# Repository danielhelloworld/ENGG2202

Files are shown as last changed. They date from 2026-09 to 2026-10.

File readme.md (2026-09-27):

# ENGG2202 MaixCAM 2 Project

This repository contains the MaixCAM 2 vision-tracking prototype, its system architecture, and a local developer workbench for device monitoring.

## Components

- [Tracker architecture](maixcam2_drone_tracker_architecture.md) — system boundaries, runtime flow, and staged development plan.
- [Person-tracking application](maixcam2_person_tracker/README.md) — Stage 1 YOLO person detection, target association, bearing estimation, and safe vision-only gimbal flow.
- [Developer workbench](workbench/README.md) — local monitoring dashboard, MJPEG stream proxy, telemetry schema, extension points, and setup instructions.
- `Daniel's code/` — existing ENGG2202 project files.

The workbench is a development monitor. Camera capture and inference remain on the MaixCAM 2; the Mac gateway displays the video and receives telemetry without taking ownership of the vision loop.

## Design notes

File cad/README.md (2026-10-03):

# 云台机械件与 MaixCAM2 快拆转接台

同步日期：2026-10-03。本目录包含相机转接台的源模型、可编辑 Fusion 文件、STEP、单件 STL、缩略图、复建脚本及验证记录，以及此前两个版本的电机支架与连接板。同步清单和 SHA-256 位于 [SYNC_MANIFEST.json](SYNC_MANIFEST.json)。

## 快速定位打印零件

- [V3 USB 优化版单件 STL](gimbalconnector/STL_单件打印_2026-10-03/01_V3_USB优化版/)：当前预留 USB 空间的版本。
- [V2 原位置加强版单件 STL](gimbalconnector/STL_单件打印_2026-10-03/02_V2_原位置加强版/)：保留相机原位置，增加底部热铆柱与侧向热铆销。
- [V2 原版单件 STL](gimbalconnector/STL_单件打印_2026-10-03/03_V2_原版/)：最初确认长边对齐的版本。
- [单件打印说明](gimbalconnector/STL_单件打印_2026-10-03/README_打印说明.md)与[打印清单](gimbalconnector/STL_单件打印_2026-10-03/打印清单.csv)。
- [离线零件索引 HTML](gimbalconnector/零件缩略图_2026-10-03/零件索引.html)：克隆或下载仓库后用浏览器打开，可筛选并访问对应 STL。GitHub 页面显示 HTML 源码，可直接查看下方 PNG 总览。

每套选择一个底座和一种相机快装板。加强版与 USB 版另需 **2 颗独立侧向热铆销**；铆销 STL 只有一颗。底部热铆柱与底座、四角固定立边与相机板分别一体打印。金属螺丝不作为打印件。

### V3 USB 优化版

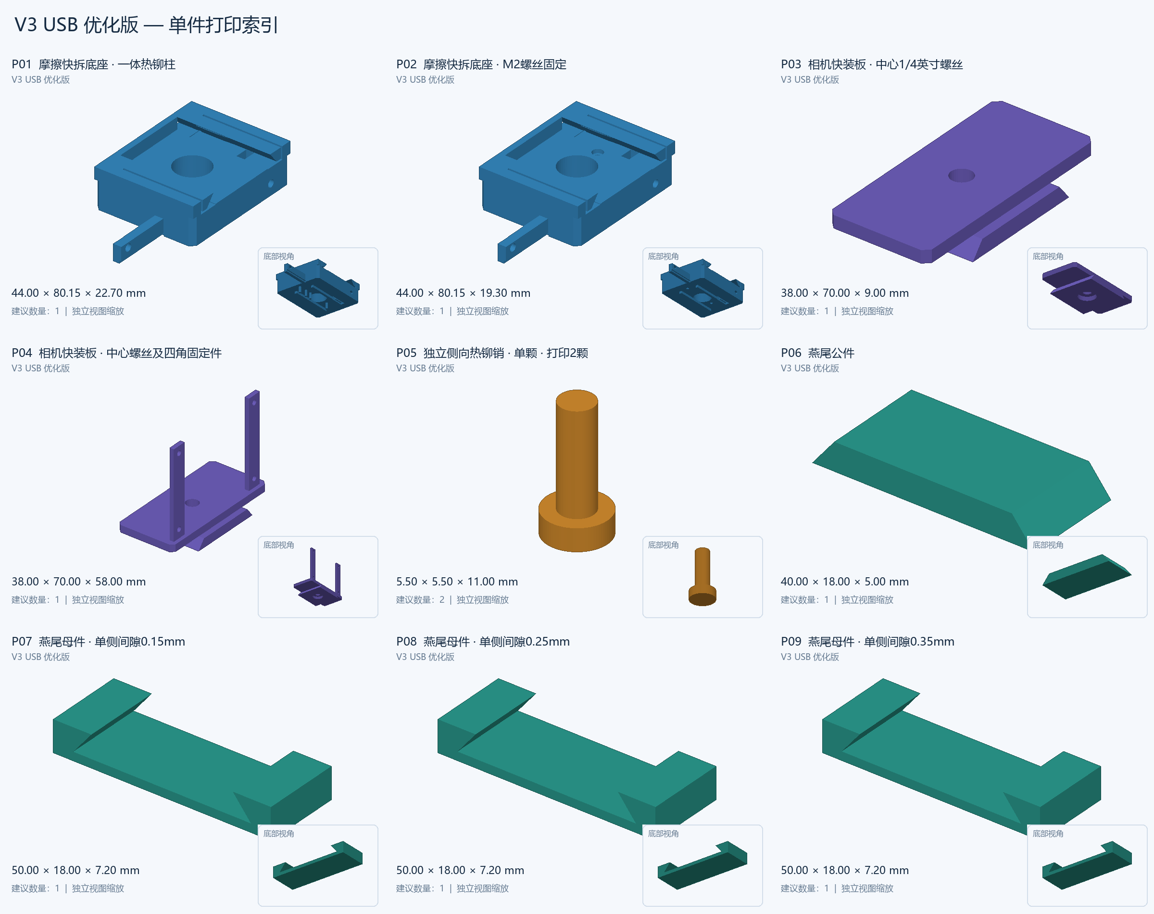
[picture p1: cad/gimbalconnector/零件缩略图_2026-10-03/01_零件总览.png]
V3 USB 单件总览


### V2 原位置加强版

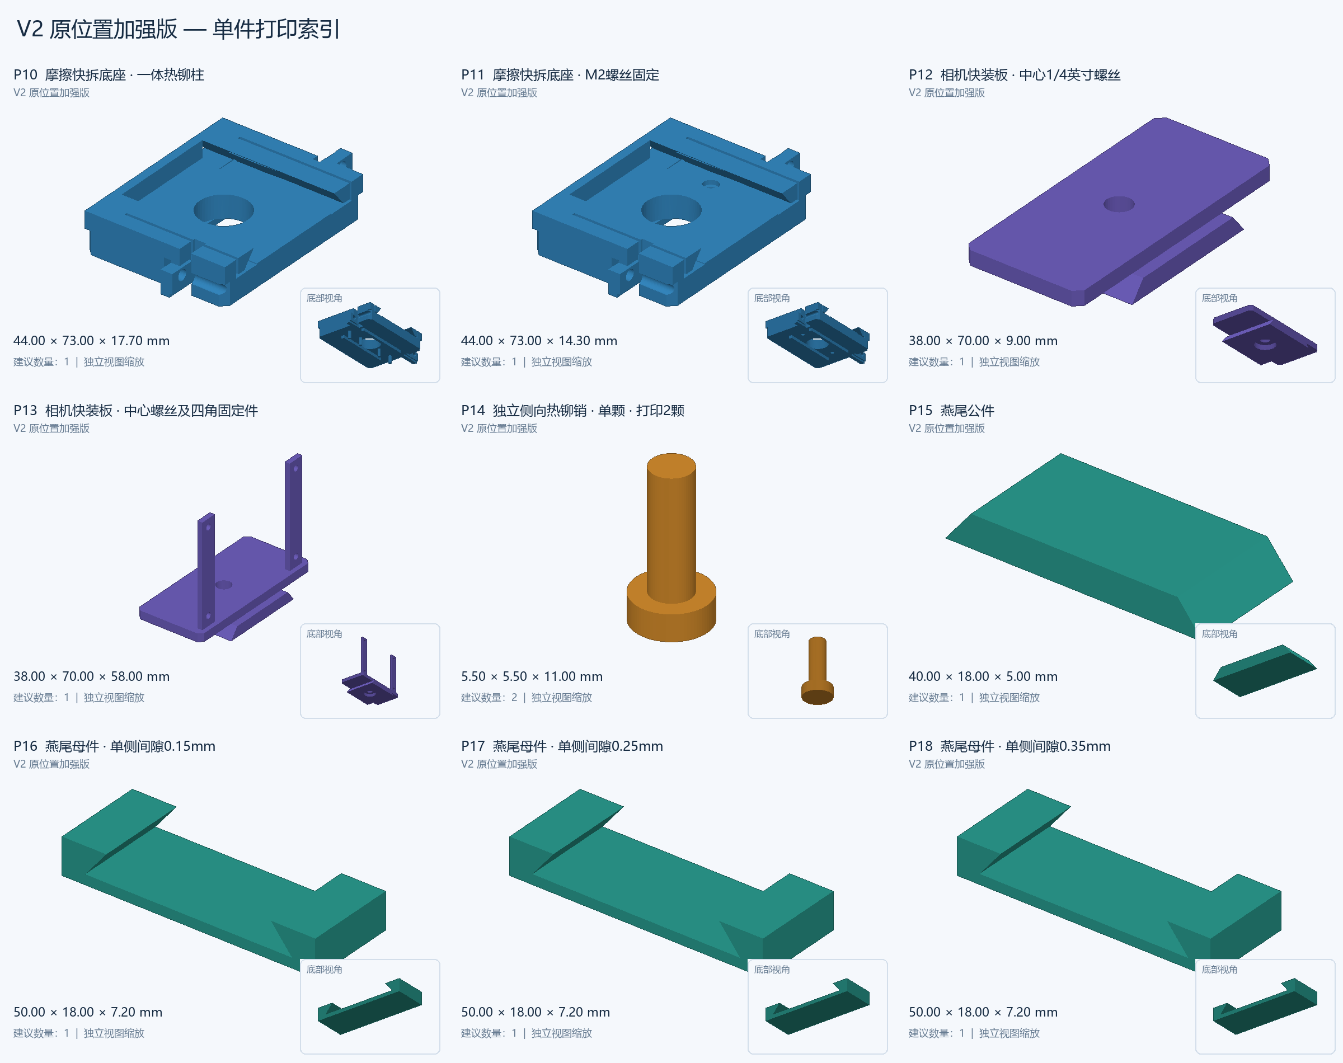
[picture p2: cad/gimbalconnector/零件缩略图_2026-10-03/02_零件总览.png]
V2 加强版单件总览


### V2 原版

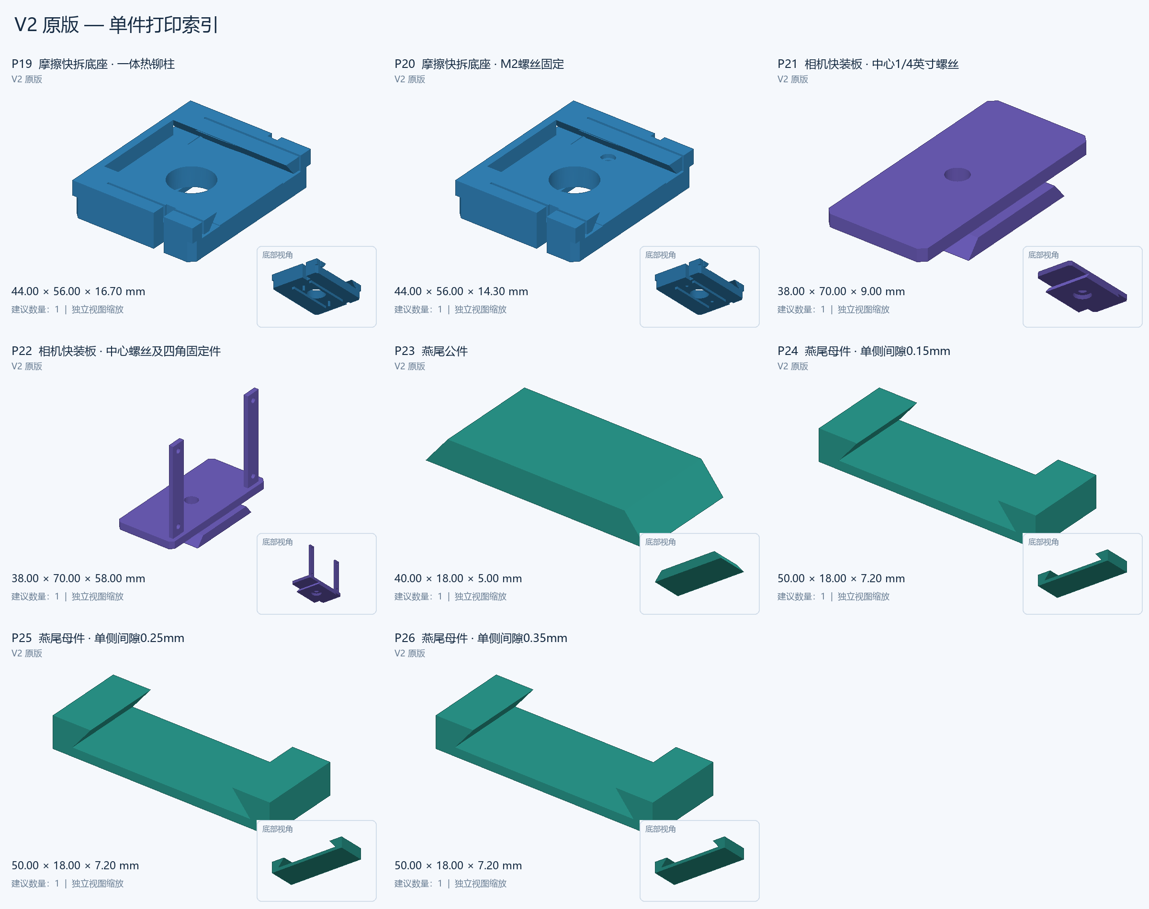
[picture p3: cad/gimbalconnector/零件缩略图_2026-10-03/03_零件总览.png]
V2 原版单件总览


V1 相机方向未采用，仍保留在历史目录，详见 [项目说明](gimbalconnector/README.md)。

## 以前两个版本的电机支架

按本地原文件名称分组，不修改模型或打印坐标：

| 版本 | 电机支架 | 连接板 |
|---|---|---|
| 原版 V1 | [电机支架.stl](motor_brackets/v1/电机支架.stl) | [电机支架连接板.stl](motor_brackets/v1/电机支架连接板.stl) |
| 第二版 V2 | [电机支架2.stl](motor_brackets/v2/电机支架2.stl) | [电机支架连接板2.stl](motor_brackets/v2/电机支架连接板2.stl) |

电机支架的 V1/V2 是这四个原始文件的版本标签，与相机快拆转接台 V1/V2/V3 独立。没有根据版本号推定两者互换兼容性。

## 编辑与验证

[转接台项目入口](gimbalconnector/README.md)介绍各版 Fusion/STEP、源模型及建模脚本；[加强版和 USB 空间说明](gimbalconnector/README_加强版与USB优化.md)介绍孔位、热铆顺序、USB 插头包络和螺丝空间。

相机转接台的 34 个单件 STL 已完成封闭性、单一连通性及尺寸保持检查，34 张缩略图逐一对应 STL，索引筛选已检查。本次四个电机支架文件仅进行原样复制、二进制 STL 格式和哈希核验。实际打印、热铆强度、摩擦保持力及完整云台运动尚未验证。

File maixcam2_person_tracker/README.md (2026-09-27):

# MaixCAM 2 Person-Tracking Gimbal

This project is the Stage 1 closed-loop validation build for a future airborne-drone tracker. It runs on a MaixCAM 2, detects one person with YOLO11, estimates the person's world bearing, and commands a two-axis WHEELTEC F32C brushless gimbal over 3.3 V TTL UART.

The project is intentionally divided so the person detector can later be replaced by a custom drone detector without changing the state estimator, loss-recovery state machine, gimbal controller, motor protocol, or telemetry pipeline.

## Current stage

Implemented:

- YOLO11 person detection using COCO class ID `0`;
- stable single-person selection when several people are visible;
- pixel-to-bearing conversion using configurable camera field of view;
- dependency-free constant-angular-velocity Kalman filtering;
- `BOOT`, `ACQUIRE`, `TRACK`, `COAST`, `SEARCH`, and `FAULT` states;
- prediction during short detector loss;
- expanding local search after the coast interval expires;
- acceleration- and rate-limited gimbal position commands;
- F32C direct multi-turn position protocol and angle feedback parsing;
- non-blocking CSV telemetry and display overlays;
- a vision-only mode for safe first execution.
- a headless default mode with one-second console status reports.

Deferred to later stages:

- MixFormerV2 appearance tracking between YOLO frames;
- frame-time gimbal-pose interpolation;
- IMU rate fusion;
- dynamic high-resolution ROI detection;
- custom drone YOLO model and appearance-based reacquisition;
- full 3D camera-to-gimbal rotation calibration.

## Safety default

`config.py` ships with:

```python
enabled: bool = False
```

The application will run the complete vision, target-selection, estimation, state-machine, overlay, and logging pipeline, but it will not open UART4 or move the gimbal.

The display is also disabled by default so the application can be started over SSH when the device's display service is already occupied. Detection count, selected-person pixels, estimated world bearing, mode, and gimbal pose are printed once per second. Set `UiConfig.enabled = True` to request the onboard display when it is available.

Do not enable the gimbal until motor IDs, axis directions, zero offsets, mechanical soft limits, wiring, and power supplies have been checked using the procedure in [docs/BRINGUP.md](docs/BRINGUP.md).

## Hardware interface

| Signal | MaixCAM 2 | F32C gimbal |
|---|---|---|
| TX | A21 / UART4_TX | RX |
| RX | A22 / UART4_RX | TX |
| Ground | GND | GND |

UART settings are `115200 8N1`. MaixCAM 2 and F32C use 3.3 V logic. Do not apply 5 V logic to the MaixCAM pins.

Use separate regulated power paths:

- F32C motors: 8-15 V, normally a 3S supply;
- MaixCAM 2: stable regulated 5 V;
- common signal ground between the two systems.

Do not hot-plug any F32C connector.

## Model

The default model path is:

```text
/root/models/yolo11n.mud
```

The model must be a MaixCAM 2 YOLO11 package containing the `.mud` file and every referenced `.axmodel` file. Its label list must use the standard COCO order, where `person` is class ID `0`.

If the model is stored elsewhere, change `ModelConfig.path` in `config.py`.

## Deployment

1. Copy the entire `maixcam2_person_tracker` directory to the MaixCAM 2 with MaixVision.
2. Confirm the YOLO11 model exists at the configured path.
3. Open and run `main.py` from the project directory.
4. Verify that a person receives a green detection box and that the mode progresses from `ACQUIRE` to `TRACK`.
5. Review the yellow predicted point and the CSV log at `/root/logs/person_tracker.csv`.
6. Stop the application and complete the motor bring-up checklist before setting `GimbalConfig.enabled` to `True`.

The Mac is a development and monitoring host only. The real-time loop runs entirely on the MaixCAM 2.

## Workbench integration

The optional [MaixCAM 2 Workbench](../workbench/README.md) provides a browser dashboard, MJPEG proxy, telemetry categories, and runtime status. It does not take ownership of the camera or inference loop.

To publish status, set the `endpoint` default inside `WorkbenchConfig` in `config.py` to the Mac USB-network address ending in `/api/telemetry`:

```python
endpoint: str = "http://10.177.5.100:8760/api/telemetry"
```

The publisher is disabled when the endpoint is empty. When enabled, it sends the newest camera, person detection, tracking, gimbal, model, and process snapshot from a background thread. A disconnected dashboard does not block the vision loop. Keep the workbench gateway bound to the Mac's USB-network interface; its telemetry endpoint is unauthenticated.

## Configuration that must be measured

The values in `config.py` are conservative starting points, not final calibration values:

- camera horizontal and vertical field of view;
- pan and tilt motor direction signs;
- logical zero offsets;
- pan and tilt mechanical soft limits;
- stable maximum rate and acceleration under the installed payload;
- detector confidence and reacquisition gate;
- coast and search timing.

## Runtime behavior

The tracker requires three consecutive person detections before commanding the gimbal. During a brief miss it enters `COAST` and commands the predicted future bearing. If the miss lasts too long or uncertainty grows too large, it enters `SEARCH` and scans an expanding region around the predicted bearing. If local search fails, the old track is cleared and the system returns to full-frame acquisition.

The F32C motors run their internal position and speed loops. MaixCAM 2 sends direct multi-turn position targets at up to 50 Hz by default and polls total-angle feedback from each motor in turn.

## Project layout

```text
main.py                         Application entry point
application.py                  Real-time orchestration
config.py                       All tunable values
domain.py                       Shared data contracts
perception/detector_yolo.py     YOLO11 adapter
perception/target_selector.py   Single-person association
estimation/camera_model.py      Pixel/bearing conversion
estimation/target_filter.py     Constant-velocity Kalman filter
control/state_machine.py        Loss and recovery behavior
control/search_pattern.py       Expanding local scan
control/gimbal_controller.py    Command prediction and motion limits
drivers/f32c_protocol.py        Binary F32C protocol
drivers/gimbal_uart.py          UART ownership and motor state
telemetry/csv_logger.py         Bounded asynchronous logging
telemetry/mjpeg_stream.py       Annotated MJPEG camera endpoint
telemetry/workbench_publisher.py Optional asynchronous desktop telemetry
telemetry/overlay.py            On-screen diagnostics
docs/ARCHITECTURE.md            Design and module boundaries
docs/BRINGUP.md                 Safe hardware activation procedure
```

## Moving to the drone stage

Replace `YoloPersonDetector` with a detector that returns the same `Detection` data type. Change the model path, class ID, label, confidence threshold, and reacquisition gate. The rest of the application does not depend on the target category.

For a distant drone, use at least a `640x480` model input, collect data through the actual lens and sky background, and expect optics and motion blur to become limiting factors before NPU throughput.

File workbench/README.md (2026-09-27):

# MaixCAM 2 Workbench

The workbench is a local developer console for a MaixCAM 2 vision project. It combines the device MJPEG camera feed with structured telemetry and process health on one page. The browser talks only to the workbench gateway; the gateway proxies the device video stream and accepts telemetry snapshots.

## Features

- Overview page for camera, detections, tracking state, gimbal feedback, and running file.
- Live camera page with the annotated MJPEG feed.
- Data explorer organized into vision, tracking, gimbal, and system categories.
- Runtime view for the active entry point, process ID, uptime, model, and device services.
- Device connection settings for IP address and video-stream port.
- Extensible JSON telemetry schema with namespaced `extensions` data.
- Server-sent events for browser updates; no third-party JavaScript packages are required.

## Architecture

```text
MaixCAM 2 tracker
  ├── MjpegStreamer ── HTTP MJPEG :8080 ───────────────┐
  └── WorkbenchPublisher ── POST /api/telemetry ───────┤
                                                       ▼
Mac Workbench gateway :8760 ── same-origin MJPEG proxy + SSE ── Browser UI
```

The MaixCAM 2 tracker remains responsible for camera capture and inference. `WorkbenchPublisher` sends a small latest-value snapshot on a background thread so a disconnected workbench does not block the vision loop. The Mac gateway keeps the newest snapshot in memory and exposes a stable browser API. The web UI renders registered categories and automatically includes unregistered metrics under extension namespaces.

## Start the workbench

The MaixCAM 2 USB network commonly gives the device `10.177.5.1` and the Mac `10.177.5.100`. Confirm the Mac address in Network settings before starting the gateway. Replace it below if the USB interface uses another address.

```bash
cd ENGG2202-github
python3 workbench/server.py --host 10.177.5.100 --port 8760 --device-ip 10.177.5.1 --video-port 8080
```

Open `http://10.177.5.100:8760/` in a browser. The gateway must bind to an address reachable by both the browser and MaixCAM 2. Bind to the Mac's USB-network interface only. The telemetry endpoint has no authentication and should not be exposed on a shared network or the public internet.

## Connect the MaixCAM 2 tracker

Set `WorkbenchConfig.endpoint` in `maixcam2_person_tracker/config.py` to the Mac USB-network address shown in the workbench's **Connection Settings** page:

```python
class WorkbenchConfig:
    endpoint = "http://10.177.5.100:8760/api/telemetry"
```

In the current code, `WorkbenchConfig` is a frozen dataclass. Set the `endpoint` field in its declaration, or provide `MAIX_WORKBENCH_URL` in the MaixCAM 2 process environment. Then start `maixcam2_person_tracker/main.py` on the device. The tracker starts its annotated MJPEG endpoint on port `8080` and publishes camera, person-detection, tracking, gimbal, model, and process metrics to the workbench.

The initial gimbal setting remains disabled. Starting the dashboard does not start or stop the tracker and does not send motor commands.

## Telemetry schema

Each `POST /api/telemetry` payload is a JSON object with a `schema_version` and category objects:

```json
{
  "schema_version": 1,
  "runtime": {"running": true, "script": "main.py", "pid": 123, "uptime_seconds": 12.5, "model_path": "/root/models/yolo11n.mud"},
  "camera": {"available": true, "width": 640, "height": 480, "fps": 15.0},
  "vision": {"person_count": 1, "selected_label": "person", "confidence": 0.87, "center_x": 320, "center_y": 240},
  "tracking": {"mode": "TRACK", "azimuth_deg": 0.2, "elevation_deg": -1.1, "azimuth_rate_deg_s": 0.0, "elevation_rate_deg_s": 0.3},
  "gimbal": {"enabled": false, "pan_deg": 0.0, "tilt_deg": 0.0, "pan_valid": true, "tilt_valid": true},
  "system": {"camera_available": true, "npu_ready": true},
  "extensions": {"depth": {"meters": 1.4}}
}
```

Use `extensions.<module-name>` for new features that do not belong to an existing category. The Data Explorer adds each namespace as a tab and lists its metrics without requiring a schema migration. For richer labels, units, charts, or controls, extend `CATEGORY_DEFS` and `METRICS` in `web/app.js`, then add the matching UI module in `web/`.

## HTTP API

| Route | Method | Purpose |
|---|---|---|
| `/api/health` | GET | Gateway health check |
| `/api/state` | GET | Latest telemetry snapshot and connection age |
| `/api/events` | GET | Server-sent state updates |
| `/api/config` | GET/POST | Read or update device IP and stream port |
| `/api/telemetry` | POST | Ingest the device telemetry snapshot |
| `/api/camera/stream` | GET | Same-origin proxy for the device MJPEG stream |

Telemetry is considered connected while a snapshot has arrived within the last three seconds. The latest snapshot is kept in memory; the gateway does not persist telemetry or camera video to disk.

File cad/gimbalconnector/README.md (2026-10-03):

# MaixCAM2 云台快拆转接台

## 选择版本

| 目录 | 用途 | 状态 |
|---|---|---|
| `output_v3_usb/` | 相机外移 20 mm，USB 侧留约 25.5 mm 空间，4 根底柱和 2 颗侧向销 | 当前 USB 优化版 |
| `output_v2_reinforced/` | 保持 V2 相机位置，增加底部热铆柱和侧向固定 | 原位置加强版 |
| `output_v2/` | 已确认的长边对齐版本 | 原版完整保留 |
| `output_v1/` | 早期方向试作 | 历史参考，未采用 |

## 打开与打印

- 在选定版本目录中打开 `MaixCAM2_quick_release_assembly.f3d`，可在 Fusion 中查看和编辑总装。
- STEP 用于交换实体，STL 用于切片；请打印选定零件，不要打印包含相机、金属支架参考体的总装。
- 加强版和 USB 版的热铆组合：`receiver_heat_stake.stl` + 一种 `camera_plate*.stl` + **2 颗** `side_heat_rivet_print_2.stl`。铆销 STL 本身只有一颗，切片数量设为 2。
- `receiver_M2_bolt.stl` 为螺钉固定的备用底座；`fit_coupon_*.stl` 为间隙试件。
- `assembly_preview.png` 为装配预览；USB 版另有 `USB_clearance_preview.png`。

详细尺寸、材料起始设置、螺丝长度和热铆顺序见 [加强版与 USB 优化说明](README_加强版与USB优化.md)及[原快拆设计说明](README_快拆转接台.md)。模型和网格检查已完成，实际摩擦保持力、热铆强度及线缆弯曲仍需试装。

## 源文件与复建工具

| 文件或目录 | 内容 |
|---|---|
| `MaixCAM2_3.0.step` | 本次采用的相机源模型 |
| `云台连接件.step` | 原云台支架源模型 |
| `3D_MaixCam2_379C_2025-09-16.step` | 较早的相机参考模型 |
| `quick_release_tool/` | Fusion 建模脚本、配置、网格校验脚本和验证记录 |
| 各版本的 `build_report.json`、`mesh_validation.json` | 几何与打印网格检查结果 |

Fusion 脚本使用 Fusion 自带的 Python 和 `adsk` API，不依赖本项目的独立虚拟环境。`validate_mesh.py` 和 `validate_optimized.py` 仅使用 Python 标准库。

当前 `command.json` 指向 USB 版复建。运行脚本会写入对应输出目录；已有文件需要另留版本时，应先调整输出目录。原相机和云台连接件文档需在 Fusion 中打开。

## 缓存清理

2026-10-03 清理记录位于 `cleanup_2026-10-03.json`。清理对象为未使用的 `cad_venv/`、脚本 `__pycache__/`、可重新生成的 `inspection.json` 和过期 `error.txt`，采用回收站保留恢复机会。版本目录、源模型、脚本和正式检查报告保持原路径。

后续运行 Python 可能重新生成 `__pycache__/`；执行 Fusion 的 `inspect` 模式会重新生成检查快照。它们不需要作为交付文件保存。

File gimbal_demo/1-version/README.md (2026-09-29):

# WHEELTEC F32C 双轴追踪控制 Demo

本 demo 根据资料包中的 2026-07-18 二自由度云台手册、2026-07-21 F32C 电机手册、STM32/TI 位置与速度例程，以及 STM32F4 绘图例程整理。它负责两台电机和视觉闭环，不包含无人机检测模型，也不包含激光发射控制。

## 轴与协议

- X 轴：底部 yaw，默认电机 ID `1`。
- Y 轴：上部 pitch，默认电机 ID `2`。
- TTL 逻辑电平 `3.3 V`，串口 `115200-8-N-1`。
- K230 TX 接云台 RX，K230 RX 接云台 TX，信号地与电机电源地必须共地。
- 电机主电源 `8~15 V`，推荐 3S；不要从 K230 给电机主回路供电。
- 所有接口禁止热插拔；滑环电流能力有限，K230 供电需先核对实际峰值电流。
- 相邻协议帧至少间隔 `1 ms`。本 demo 默认 `2 ms`。
- 高频修改目标位置使用手册建议的“多圈位置直通模式”`0x0003`。

默认的 Y 轴死角宽度为 `120°`，中心位于逻辑 `180°`（云台后方），并预留两侧各 `2°` 安全边界，因此控制器实际允许 `-118°~+118°`。可通过 `--y-dead-width`、`--y-dead-center` 和 `--y-dead-margin` 修改。如果实际机械零点不同，应先低速点动确认死角中心再改参数。

## 第一次运行

先不要连接电机，用协议模拟验证：

```powershell
cd C:\Users\w.yingxi\Desktop\ENGG2202\f32c_gimbal_python_demo
python demo.py --dry-run manual --x 15 --y 10
python demo.py --dry-run simulate --seconds 3
python -m unittest -v
```

PC 通过 USB-TTL 控制时：

```powershell
python -m pip install -r requirements.txt
python demo.py --port COM5 --speed 20 manual --x 5 --y 5
```

首次带硬件测试请把云台固定牢，移除激光器和贵重负载，把角度限制在小范围。若方向相反，使用 `--x-sign -1` 或 `--y-sign 1`，不要交换电源线。

## 接入 K230 检测结果

PC/进程间可以向标准输入逐行发送检测框中心：

```powershell
'{"cx":400,"cy":220,"width":640,"height":480}' | python demo.py --port COM5 track-stdin
```

未检测到目标时发送：

```json
{"detected": false, "width": 640, "height": 480}
```

在 K230 上，按开发板的 pinmux 创建 `machine.UART` 后，将 YOLO/检测器输出的目标框中心接到 `k230_integration.run_tracking()`。检测回调的返回值为：

```python
(target_center_x, target_center_y, frame_width, frame_height)
```

没有目标则返回 `None`。如果同一帧有多个候选目标，应在检测侧先固定一个 track ID，避免控制器在目标间跳变。

## 控制流程

1. 发送一次唤醒字节并等待电机启动 1.5 秒。
2. 依次使能 ID 1 和 ID 2。
3. 两轴选择多圈位置直通模式，设置位置运动速度。
4. 分别读取当前多圈角度，将其作为软件零点，避免启动时突然回到电机上电零点。
5. K230 每帧给出检测框中心；控制器把像素误差按相机 FOV 换算为角度误差，经比例、像素死区和角速度限制后下发两轴目标。
6. Y 轴命令始终被限制在配置的连续安全区间内。
7. 退出时发送两轴失能命令。

## 重要边界

- 代码只解决“检测结果到双轴角度”的闭环。检测模型、目标身份保持、云台/相机外参、镜头畸变和飞行目标提前量需要在实际系统中标定。
- 相机水平/垂直视场角默认 `70°/43°`，必须替换为实际镜头参数。
- 激光对眼睛、车辆和航空器均有严重风险。调试时仅使用低功率可见指示光并配合封闭式挡光靶；不要照射真实飞行器或天空。

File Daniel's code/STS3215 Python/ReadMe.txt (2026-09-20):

Hi guys, This is Kelvin. Hope you are doing well with your miniprojects.

If you are working on the STS3215 projects and got stuck, you may refer to this folder.
You can either run the code inside VS code or directly in the terminal just like what we did in the workshops

Here is a guide of what the files inside this folder does:

"ENGG_1101_STS3215" is the main folder that stores all the python scripts and library packages
	Inside the folder there are 3 important python scripts:
	
	1. "change_id.py" in which you have to input the orginal and new ID:

		SCS_ID = 1            # SCServo ID : 1
		NEW_ID = 2             #Change the Servo ID

	2. "ENGG1101_2servo_write.py" where I already helped you setup ID = 1 and ID = 2 for the two servos you need
		what you need to do is just run the code and input the positions for servo 1 and servo 2
		(For your projects you would need to modify the input part to some snsor vales - ToF or camea)

	3. "read_write.py" - this is the original python code that reads and write the position for a single STS3215 servo. 
		you can take some reference from it and modify using the help of AI

Also, one IMPORTANT thing:
For each of the python scripts I mentioned above, you would need to change the BAUDRATE as well as the DEVICENAME (which is the communication port on the raspberry pi)

You would have to change these lines of code:(Set Baudrate to 115200 and check the raspberry pi & servo driver communication port using the "dmesg" command in terminal)  

	BAUDRATE   = 115200           # Must match the ESP32's serial forwarding baudrate
	# Check Raspberry Pi serial port with "dmesg" command and look for the port connectng to cp210x
	DEVICENAME = '/dev/ttyUSB1'   # Change to your port (e.g., '/dev/ttyUSB0', 'COM3')  

*** If you have any futher questions, feel free to come to the helpdesks on tuesdays and fridays from 1400 to 1700. You could also email me and ryan for more helpdesk sessions or help ***

P.S. Ryan's email: ruoyu@hku.hk ; My email: ckchancd@hku.hk

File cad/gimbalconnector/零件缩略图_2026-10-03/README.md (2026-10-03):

# 单件打印缩略图

用浏览器打开 `零件索引.html`，可按版本、类型和名称筛选，点击“获取 STL”访问对应文件。默认显示当前 V3 USB 版。

`缩略图/` 包含每个单件的 PNG，`01_零件总览.png` 至 `04_零件总览.png` 为各版总览。图片来自真实 STL 网格，每件有上方和底部两个视角。

原有项目文件均未改动。请保持本目录与 `STL_单件打印_2026-10-03/` 并列，以便索引内的 STL 链接正常工作。

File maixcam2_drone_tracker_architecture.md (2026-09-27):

# MaixCAM 2 Drone-Tracking System Architecture

The approved architecture has been converted into an English implementation project at:

- [Project README](maixcam2_person_tracker/README.md)
- [Software architecture](maixcam2_person_tracker/docs/ARCHITECTURE.md)
- [Hardware bring-up procedure](maixcam2_person_tracker/docs/BRINGUP.md)

## System direction

The final system uses a MaixCAM 2, one camera, and a two-axis WHEELTEC F32C brushless gimbal. MaixCAM 2 owns perception, target-state estimation, loss recovery, and gimbal target generation. Each F32C motor retains responsibility for its internal position and speed loops.

The runtime chain is:

```text
Camera
  -> YOLO detector
  -> single-target association
  -> world-bearing Kalman filter
  -> TRACK / COAST / SEARCH state machine
  -> bounded position trajectory
  -> F32C direct multi-turn position commands
```

Stage 1 uses the COCO `person` class to validate the complete visual closed loop. The later drone model will implement the same `Detection` interface, allowing the estimator, controller, motor protocol, and telemetry modules to remain unchanged.

## Key design decisions

- Real-time control runs entirely on MaixCAM 2. The Mac is used only for development, monitoring, and log retrieval.
- Prediction is performed in installation-frame azimuth and elevation rather than image pixels.
- Short losses enter `COAST`; longer losses enter an expanding local `SEARCH`; failed local recovery clears the old identity and returns to full-frame `ACQUIRE`.
- F32C direct multi-turn position mode is used for frequent target updates and safer hold behavior after software stops sending commands.
- UART4 on MaixCAM 2 uses A21/A22 at 115200 8N1 with motor IDs 1 and 2.
- Motor and MaixCAM power paths are separately regulated and share signal ground.
- Gimbal output is disabled by default in software until axis signs, zero offsets, and mechanical limits are verified.

The implementation project documents contain the detailed module contracts, state transitions, source layout, safety behavior, calibration parameters, and Stage 1 acceptance criteria.

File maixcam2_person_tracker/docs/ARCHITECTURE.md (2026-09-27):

# Software Architecture

## Design objective

The Stage 1 application proves that perception, angular state estimation, loss handling, and F32C command generation can form a stable closed loop around one person. Target-specific code is kept behind the detector adapter so a drone model can replace the person model later.

## Runtime data flow

```mermaid
flowchart LR
    Camera --> YOLO[YOLO11 person detector]
    YOLO --> Selector[Single-person selector]
    Selector --> CameraModel[Pixel-to-bearing conversion]
    MotorFeedback[F32C angle feedback] --> CameraModel
    CameraModel --> Filter[Angular Kalman filter]
    Filter --> StateMachine[Tracking state machine]
    StateMachine --> Search[Prediction or search target]
    Search --> Limiter[Rate and acceleration limiter]
    Limiter --> UART[F32C UART driver]
    UART --> Motors[Pan and tilt motors]
    Filter --> Telemetry[Overlay and CSV telemetry]
    StateMachine --> Telemetry
```

## Module boundaries

### `perception`

`YoloPersonDetector` is the only module that knows about MaixPy YOLO result objects. It converts every accepted result into the project's immutable `Detection` type.

`TargetSelector` owns target identity at the simple Stage 1 level. During acquisition it favors a confident, large, central person. After a track exists, it gates candidates by angular distance from the predicted bearing and adds image-space overlap as a continuity cue.

The future MixFormerV2 adapter belongs in this layer. It should produce the same `Detection`-like image observation and must not command the gimbal directly.

### `estimation`

`CameraModel` converts a bounding-box center into relative ray angles and then into installation-frame azimuth and elevation using gimbal feedback. Stage 1 uses independent pan and tilt angle addition. A later calibrated 3D rotation can replace this implementation without affecting downstream modules.

`TargetFilter` contains two independent two-state Kalman filters:

```text
azimuth axis:   [position, angular_rate]
elevation axis: [position, angular_rate]
```

The process model assumes constant angular velocity with white angular-acceleration noise. Position covariance grows during missing measurements and becomes an input to the loss-recovery decision.

### `control`

`TrackingStateMachine` is the only authority for operating mode. Perception code reports whether a measurement exists; it does not decide whether the system should coast, search, or fault.

`ExpandingSearchPattern` creates a bounded two-axis Lissajous scan around the last predicted bearing. Its amplitude grows with search time.

`GimbalController` adds a short prediction horizon and applies software angle, rate, and acceleration limits. It outputs a `GimbalCommand` and contains no UART code.

### `drivers`

`f32c_protocol.py` is a pure binary codec. It creates frames, calculates XOR BCC values, and incrementally parses nine-byte feedback frames.

`F32CGimbal` exclusively owns UART4. No other module may call the UART API. It performs pin mapping, initialization, command serialization, feedback polling, coordinate sign conversion, hold, fault, and shutdown behavior.

`VisionOnlyGimbal` implements the same interface with a fixed zero pose and no hardware output. This keeps the entire application path active while motion is disabled.

### `telemetry`

`AsyncCsvLogger` uses a bounded queue. If storage cannot keep up, diagnostic samples are discarded instead of delaying the control loop.

`overlay.py` draws the selected detection, filtered prediction, operating mode, gimbal pose, and angular state.

## State machine

```mermaid
stateDiagram-v2
    [*] --> BOOT
    BOOT --> ACQUIRE: Both motor angles are valid
    BOOT --> FAULT: Feedback boot timeout
    ACQUIRE --> TRACK: Consecutive person observations
    TRACK --> COAST: Observation missing
    COAST --> TRACK: Observation restored
    COAST --> SEARCH: Timeout or excessive uncertainty
    SEARCH --> TRACK: Confirmed local reacquisition
    SEARCH --> ACQUIRE: Local search timeout and track reset
    ACQUIRE --> FAULT: Feedback stale
    TRACK --> FAULT: Feedback stale
    COAST --> FAULT: Feedback stale
    SEARCH --> FAULT: Feedback stale
```

When the gimbal is disabled in configuration, `VisionOnlyGimbal` supplies a valid stationary pose so the perception and state-estimation path can still advance through the same modes.

## Motor operating mode

The driver selects F32C direct multi-turn position mode (`0x0003`) after enabling each motor. Position targets use function `0x02` with signed degrees multiplied by ten. The configured RPM value limits motion while the F32C internal loops perform the low-level control.

Direct position mode was selected because it accepts frequent target updates and holds the last target if application updates stop. A raw speed-mode outer loop would create a greater runaway risk after a process failure.

## Timing

The image loop runs as quickly as camera capture, inference, and display allow. Position commands are rate-limited separately by `command_period_ms`. Angle feedback requests alternate between the two motor IDs. All UART frames pass through a single writer and observe the configured inter-frame gap.

Stage 1 timestamps an image immediately after `camera.read()` and uses the most recent motor angles. A later implementation should keep a timestamped gimbal-pose ring buffer and interpolate pose at the sensor exposure timestamp.

## Safety behavior

- Mechanical angle limits are applied before every position command.
- Command position, velocity, and acceleration are bounded in software.
- Missing or stale feedback enters `FAULT`.
- The default fault policy holds the current angle and then disables both motors.
- Normal application exit holds the latest position unless `disable_on_normal_exit` is enabled.
- Physical power isolation, fusing, hard stops, and an operator-accessible power cut-off remain hardware responsibilities.

## Extension points

The next implementation steps should preserve the current data contracts:

1. add a MixFormerV2 adapter under `perception`;
2. add timestamped motor-pose interpolation under `estimation`;
3. add dynamic high-resolution ROI management;
4. replace `YoloPersonDetector` with `YoloDroneDetector`;
5. add appearance similarity to reacquisition scoring;
6. fuse IMU angular rate with encoder pose;
7. move measured hot paths to MaixCDK only if profiling justifies it.

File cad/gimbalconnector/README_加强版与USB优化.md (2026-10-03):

# V2 加强版与 V3 USB 空间优化版

2026-10-03。本次保留 `output_v2/` 的已完成文件，分别另存两版：

| 版本 | 相机相对原 V2 位置 | 底部一体热铆柱 | 上方两孔固定 | 文件目录 |
|---|---|---|---|---|
| 已保留的 V2 | 原位置 | 2 根 Ø2.1 × 4.5 | 未使用 | `output_v2/` |
| V2 加强版 | 原位置与原高度 | 4 根 Ø2.2 × 5.5 | 2 颗独立 Ø3.0 侧向热铆销 | `output_v2_reinforced/` |
| V3 USB 优化版 | 向连接板自由端外移 20；承托高度再提高 5 | 4 根 Ø2.2 × 5.5 | 同上 | `output_v3_usb/` |

两版都保持相机长边沿连接板长方向、向侧面抽出的摩擦燕尾快拆、中心 1/4 英寸金属螺丝孔，以及可选的四角螺丝辅助立边。相机原模型与原云台支架不修改。

## 选用与文件

- 要保持原位置、增加固定点：选 V2 加强版。
- 主要需要 USB 插头空间：选 V3 USB 优化版。
- 每个目录有 Fusion 总装 `MaixCAM2_quick_release_assembly.f3d`、STEP 总装、零件 STEP/F3D/STL、预览和几何报告。
- 使用热铆版时，打印 `receiver_heat_stake.stl`、一种 `camera_plate*.stl`，以及 **2 颗** `side_heat_rivet_print_2.stl`。该 STL 文件只含一颗铆销，切片时数量设为 2。
- `receiver_M2_bolt.stl` 是底部可拆卸螺钉固定的备用版本，上方侧向孔与热铆销保留。
- 三档刚性燕尾试件与公件可用于打印尺寸筛选。完整底座的弹性肋摩擦力仍需实际打印试装。
- 不要把包含相机参考外壳和隐藏备用件的 Fusion 总装作为单个实体打印。

## 热铆柱与原支架上方两个孔

原长槽只有 2.4 mm 宽，直接使用更粗的柱会无法穿入。因此柱径从 2.1 增至 2.2，数量从 2 增至 4，长度从 4.5 增至 5.5。穿过 2 mm 金属板后，约 3.5 mm 伸出材料可供成头。底部目标铆头可先按约 Ø4～4.5、厚约 0.8～1.0 试压，再按材料流动和实际夹紧调整，不能靠热压整个滑轨来成形。

相对原支架长槽中心，V2 加强版四柱 Y=-22、-10、10、22；V3 四柱 Y=-4、4、10、32。所有柱 X=0，均位于原长槽范围内，并避开外移后的中心螺丝工具通道。打印公差仍需实际试装；不要强行压入过大的打印柱。

原两个较大的侧向预留孔是 Ø3.2，孔轴沿 X，中心位于 `(Y,Z)=(-28.15,5.0)` 和 `(36.85,5.0)`。新底座增加对应耳座，留 Ø3.2 通道及 Ø5.8 × 2.2 内侧头部凹位；通道贯穿可能挡住销杆的底座部分。独立热铆销杆径 Ø3.0，预制内侧头 Ø5.5 × 2，杆长 9。装配后杆端约伸出金属侧耳 3 mm。

**装配顺序：先让四根底部竖柱穿过长槽，再从内侧插入两颗独立侧向销，最后分别热压成头。** 侧向销不能做成底座一体柱，否则刚性支架无法同时沿两个互相垂直的方向套入。销穿过打印耳座和原金属侧耳，预制头朝内；加热成头的位置朝外。侧向固定也用于限制底座沿长槽方向移动。

## V3 的 USB 空间

本地相机 STEP 中 USB-C 接口在原 X 负端，V2 旋转后朝连接板电机安装盘方向。外移 20 mm 后，这一侧相机外壳面到安装盘最近面的轴向距离，由约 5.525 增为 **25.525 mm**。

V3 增加一个隐藏的 `USB_plug_keepout_24x14x14` 参考体，用于检查约 24 mm 长、14 mm 宽、14 mm 高的假定插头空间。这是设计包络，**不是你实际 USB 插头的模型**。沿插入方向留约 1.5 mm 到安装盘，靠相机面留 0.1 mm；检查结果在 `build_report.json` 中。`USB_clearance_preview.png` 用绿色显示这个空间，参考体不进入默认 STEP 装配。

外移后快拆轨道会经过原侧耳，轨道承托高度再提高 5 mm，并做局部避让，保留侧耳上方约 5.3 mm 的轨道连接桥。相机底部承托面 Z=21.3，公燕尾底面 Z=12.3，比原侧耳最高处 Z=11.5 留出 0.8 mm 高度间隙；侧面抽出全程均可越过这个侧耳。相机长边方向不变。较长插头、较粗应力释放护套或线缆弯曲半径超出这个包络时，仍需实际比对。外移也改变云台负载力臂，装配后应重新检查平衡与运动范围。

## 螺丝、打印与验证

中心螺丝 Ø6.8 通孔、Ø14 × 3.5 螺丝头凹位、承压面到相机底面 5.5 mm 保留。四角辅助孔距 55.67811 × 40.27408，辅助件厚 2.4；使用原规格的适当加长螺丝，实际牙距与有效伸入深度按实物确认。详细螺丝与试装说明见原 `README_快拆转接台.md`。

底座肩部、柱和长耳座下方按切片预览安排支撑；保持燕尾面和弹性释放缝通畅。独立铆销的大头朝打印床，杆轴竖直。只对柱端、销端局部加热，避免摩擦滑轨变形。先进行无通电手动装配和反复插拔，再检查实际 USB 插头及线缆、静态保持力和云台全范围。

几何报告用于检查实体与包络碰撞；STL 报告用于尺寸和封闭网格检查。**没有进行打印、热铆强度、保持力或云台运动实测。** 默认只对这一件原支架与相机外壳验证，不代表完整云台的动态包络。

## 复建

脚本 `quick_release_tool.py` 调用独立的 `build_optimized.py`；原 `build_adapter.py` 保留。`command.json` 使用 `{"mode":"build_reinforced","variant":"reinforced"}` 或 `{"mode":"build_usb","variant":"usb"}`。原相机 `MaixCAM2_3.0` 与导入的云台连接件文档需保持打开。每次建立新文档，优化版只写入自己的输出目录。

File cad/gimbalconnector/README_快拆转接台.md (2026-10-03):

# MaixCAM2 相机与现有云台支架的快拆转接台

2026-10-03，V2 方向修正版。相机 66.25 mm 长边沿原连接板的 Y 方向，镜头朝 +X；旧 V1 方向未采用。本地设计文件位于 `output_v2/`；建模脚本位于 `quick_release_tool/`。

## 结构与文件

- `MaixCAM2_quick_release_assembly.f3d`：Fusion 时间线装配，包含实际相机外壳及原云台连接件参考实体，默认显示热铆底座和四螺丝辅助板。备用版本、试件隐藏在浏览器中。
- `receiver_heat_stake.stl/.step/.f3d`：快拆座，两根 Ø2.1 mm 一体热铆柱穿过原支架长槽；双侧定位肩限制左右晃动。
- `receiver_M2_bolt.stl/.step/.f3d`：相同滑轨的螺钉固定版，两个 Ø2.4 mm 通孔及 Ø4.5 × 1.7 mm 螺丝头沉孔。使用 M2 螺钉、背面垫片和螺母夹紧长槽，螺丝头不得高于滑轨底面。
- `camera_plate.stl/.step/.f3d`：底部中心 1/4 英寸金属螺丝固定版。
- `camera_plate_four_screw.stl/.step/.f3d`：在上述快拆板上增加两条正面立边，对应四角原螺丝，可辅助防转和固定。
- `fit_coupon_male.stl` 和三种 `fit_coupon_gap_0.15/0.25/0.35.stl`：18 mm 长的刚性燕尾截面试件，用于检查实际打印尺寸和滑动间隙，不能代表完整弹性压条的保持力。
- `build_report.json`：实体尺寸、体积、干涉检查和导出结果。`mesh_validation.json`：导出 STL 的尺寸、封闭性和连接性检查。

打印时只导入选定的两个零件 STL，不要打印整套装配或相机参考壳体。Fusion 总装包含隐藏备用件，STEP 总装导出默认显示的装配组合；整套装配均不能当成单一打印实体。

## 从本地模型读取的接口

所有尺寸为 mm。原支架装配坐标中的水平承托面是 Z=48.46149；长槽中心 X=-1.68997、Y=130.07520，槽宽 2.4，两端圆弧中心距 65，承托板厚 2。槽所在支架两侧相对槽中心分别为 X=-6、X=8。

转接座把长槽中心定义为本地 X=0、Y=0，承托面为 Z=0。两根固定柱或螺钉孔位于 `(0,-16)`、`(0,16)`，中心距 32。定位肩与原支架侧面各留 0.3 mm 间隙。热铆柱从座底向下伸出 4.5 mm，穿过 2 mm 支架后约有 2.5 mm 可供成头。

相机原始坐标中的底部平面是 Z=-24.86，中心螺孔轴线为 X=0、Y=4.25。将这个螺孔中心对齐快拆板中心，承托板顶面为 Z=16.3。相机绕 Z 转 90°，其长边沿连接板的 Y 方向。为避开连接板两端高 11.5 mm 的凸起，V2 底座增加对应缺口，滑轨和相机整体提高 3 mm；快拆板主承托部分底面 Z=12.3，与凸起顶端留 0.8 mm 高度间隙。底座平台厚度为 7 mm。原模型螺孔细节不能替代实物螺纹确认；本设计按用户提供的 1/4 英寸螺孔留金属螺丝通孔，不打印螺纹。

四角正面螺孔中心 X=-27.83906 / +27.83905、Z=-20.13704 / +20.13704，即孔中心距 55.67811 × 40.27408。辅助立边位于相机镜头面两侧，绕开中间镜头。V2 中镜头面朝 +X，四孔位置转为 Y=-27.83906 / +27.83905、Z=21.02296 / 61.29704，立边内侧 X=11.60043。原孔在模型中的过孔直径为 2.5；辅助件使用 Ø2.8 通孔。**实际原螺丝直径、牙距、原啮合长度仍需实测**，换同规格螺丝时增加约 2.4 mm 长度补偿立边，不能仅由过孔直径认定螺丝规格。四螺丝版也保留中心 1/4 英寸固定孔。

## 快拆方式

快拆板从底座的 **+X 开口端沿 -X 滑入**，-X 端有硬挡块；向 +X 拔出。滑轨与相机沿竖直轴转过 90°，相机长边沿支架 Y 方向；底部定位肩、热铆柱及螺钉孔仍沿原长槽布置。两侧燕尾限制抬起和侧移；沿退出方向的保持力来自两侧打印弹性压条及渐进摩擦肋。没有额外锁紧杆、磁铁或卡扣锁舌。拔出时握住承托板两侧外伸边，沿 +X 平直退出。

燕尾底宽 40、顶宽 32、高 5，斜面水平/垂直比例 0.8:1。常规轨面每侧名义间隙 0.25；最后接触段每侧名义弹性干涉 0.10。压条有 0.9 mm 侧缝及 0.8 mm 底部释放缝。压条的模型干涉是有意的，要求打印后弹性变形；刚性零件的几何检查不能证明摩擦保持力。

## 中心螺丝空间

Ø6.8 通孔，底面 Ø14 × 3.5 深螺丝头凹位；底座有 Ø15 工具通道。螺丝从快拆板下方插入，在把板滑入底座之前拧入相机。优先选头部直径 ≤13.5、厚度 ≤3.3 的金属相机螺丝，确保头部不突出燕尾底面。

从螺丝头承压面到相机底面约 5.5 mm。原模型底部孔区深度约 4.5 mm，先按 **实际伸入量约 3～4 mm** 检查，避免顶到孔底：螺丝头承压面以上长度减去 5.5 mm 及垫片厚度，就是实际伸入量。实际牙距、可用深度及是否需要垫片，以手动试装为准，不直接据此选择一个固定标准长度。

## 打印与试装

1. 用最终材料和同一套切片设置先打印截面试件，检查三档间隙。试件用于尺寸筛选；完整底座仍需验证弹性肋的摩擦力。当前完整底座采用每侧 0.25 mm 轨面间隙。
2. 起始设置可用 PETG、0.2 mm 层高、5 道外墙、40～60% 填充。先试装再按实际机器和材料调公差。承托板可倒置，以大平面朝打印床；四螺丝立边版需在切片中安排支撑。底座底部肩和热铆柱有下伸部分，使用仅底部所需的支撑，燕尾接触面和弹性释放缝不要被支撑堵住。
3. 去除毛刺，检查两条压条可以轻微偏转且释放缝通畅。不要用整体缩放调整孔距或滑轨，只改脚本尺寸后重建。
4. 先固定快拆座到支架。热铆时分次、局部压热成头，目标是背面约 Ø3.5～4 的平头，并保留支架与底座夹紧；不要把整个滑轨放在加热板上压热，以免摩擦面变形。穿长槽的柱不能靠孔壁阻止纵向滑动，纵向固定依赖铆头夹紧产生的摩擦。螺钉版可拆卸并能重新紧固。
5. 将快拆板中心金属螺丝固定到相机，再按需使用四颗同规格加长螺丝固定辅助立边。
6. 无通电状态下手动试装：板必须能连续滑入、抵住挡块，抬起无脱轨，向开口方向施力不应自行滑出。重复插拔后检查保持力；随后逐步测试实际线缆拉力和云台加减速。**本次没有打印、承载或云台运动实测**，纯摩擦结构不能从 CAD 直接保证长期保持力。

## 验证边界与复建

以本地相机外壳与这一个云台连接件做安装位置检查；未把完整两轴云台、线缆与所有转角纳入动态包络。输出目录的报告给出已验证项目，实际运动全范围仍需手动确认。重合承托面在布尔检查遇到内核错误时，以 (-0.005,+0.005,+0.005) mm 微偏移复核，仅用于检查，不移动实际装配。

在 Fusion 的“脚本和附加模块”中添加 `quick_release_tool` 目录。原始 `MaixCAM2_3.0` 文档和导入的 `云台连接件.step` 文档保持打开，`command.json` 的 `mode` 为 `build`。每次运行创建新文档，原文档不改动；导出写入 `output_v2`，需要保留不同版本时先修改 `OUT` 目录。模型通过草图、拉伸、放样与基准实体副本组成，可沿时间线编辑。

脚本依据 Autodesk 的 [STL 导出示例](https://help.autodesk.com/cloudhelp/ENU/Fusion-360-API/files/STLExport_Sample.htm)及[临时 BRep 布尔检查接口](https://help.autodesk.com/cloudhelp/ENU/Fusion-360-API/files/fusion_TemporaryBRepManager_booleanOperation.htm)实现本地导出与几何验证。

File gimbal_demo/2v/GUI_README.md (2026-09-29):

# F32C 双轴控制 GUI

## 启动

在 VS Code 终端进入本目录：

```powershell
python -m pip install -r requirements.txt
python gimbal_gui.py
```

没有连接硬件时，可以先运行模拟模式检查界面：

```powershell
python gimbal_gui.py --demo
```

## 实机操作顺序

1. 固定云台，暂时拆除危险或贵重负载。
2. 断电完成 USB-TTL 与云台接线，确认 3.3V TTL、TX/RX 交叉、信号共地。
3. 把相机调整为垂直地面的位置。连接时程序会把这一物理姿态记录为 Y 轴软件 `0°`。
4. 给电机主回路供电，在 GUI 选择对应 COM 口。初次测试建议速度 10～20 RPM、加速度 50～100。
5. 点击“连接并使能”。程序自动选择“多圈位置 T 型轨迹”，设置速度和加速度，并读取两个电机的总角度作为软件零点。
6. 等待实时 X/Y 相对角度出现，再用滑块或数值输入改变目标。
7. 点击“电机失能”只关闭电机扭矩，不关闭串口；实时位置仍会持续更新。点击“电机使能”可恢复控制，原软件零点保持不变。
8. 点击“断开串口”或关闭窗口时，程序会先失能两台电机再关闭串口。

## 平滑运动与停止震荡

GUI 使用厂家推荐的“多圈位置 T 型轨迹模式”，而不是位置直通模式。速度和加速度可以在连接后修改：

- 速度越高，到达目标越快，但大负载更容易出现超调；
- 加速度决定启动和停止冲量。轨迹不平滑或停止冲击大时，先降低加速度；
- X 轴 GUI 指令范围为 `-360°～+360°`，通过多圈绝对角度协议发送；
- Y 轴仍有相对软件零点 `-100°～+100°` 的驱动硬限制。

## 速度环 PID 调试

厂家资料给出的速度环 PID 范围为 `0～256`，经验范围为 KP `5～50`、KI `5～100`。GUI 不会在连接时自动覆盖电机 PID：

1. 选择 X 或 Y 轴；
2. 从较小的 KP/KI 开始，点击“临时应用”；
3. 每次只小幅增加一个参数并观察到点超调、回摆和高频振动；
4. 效果确认后再使用“应用并掉电保存”。保存操作有二次确认。

负载下到点超调或往回修正过大时，可小幅增加速度环 KP，再视情况增加 KI。参数过大会引起空载高频振动。位置环 PID 按厂家说明通常不需要修改，因此 GUI 只开放速度环。

## 安全层级

Y 轴允许范围固定为相对软件零点 `-100°～+100°`：

1. Y 滑块只显示该范围；
2. 数值输入会拒绝区间外数值；
3. GUI 到后台线程的接口会再次检查；
4. 基础驱动在生成任何位置帧之前进行最终检查。

因此越位命令不会写入串口。X 轴的 `-360°～+360°` 是 GUI 操作范围；F32C 多圈协议本身支持更大的累计角度。

## 零点注意事项

限制是相对于每次连接时捕获的软件零点计算的。连接前相机必须处于“垂直于地面”的真实零位；否则 ±100° 范围会相对错误的物理姿态偏移。

GUI 显示的“电机总角度”是控制器反馈的原始累计角度参考，不要求它本身等于 `0.0°`；程序把这个读取值映射为界面中的相对 `0.0°`。重新连接后会重新读取，软件零点不写入电机 Flash。

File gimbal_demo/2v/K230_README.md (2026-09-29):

# K230 / CanMV 接入说明

K230 固件常见的是 MicroPython/CanMV 环境，请使用独立文件 `k230_f32c_demo.py`；它不依赖 `pyserial`、`dataclasses` 或 CPython 类型注解。`k230_integration.py` 适合运行完整 CPython 的 K230 Linux 系统，不用于精简的 CanMV 固件。

先按具体 K230 开发板的手册完成 UART pinmux，再建立 `115200-8-N-1` UART。不同开发板的 UART 编号和引脚不同，不能直接照抄引脚号。典型调用结构如下：

```python
from machine import UART
from k230_f32c_demo import run_tracking

uart = UART(UART.UART1, 115200, bits=8, parity=None, stop=1, timeout=20)

def detect_drone_center():
    # 用实际 K230 检测器替换此处。
    # 有目标：return (cx, cy, image_width, image_height)
    # 无目标：return None
    return None

run_tracking(uart, detect_drone_center, y_dead_zone_deg=120.0)
```

如果图像右侧目标导致云台向左转，修改 `K230Tracker` 的 `x_sign` 为 `-1`；上下方向相反则修改 `y_sign`。首次通电应移除危险负载，并用小角度、低速验证方向和 Y 轴机械死角。

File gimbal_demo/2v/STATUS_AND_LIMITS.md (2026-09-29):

# 实时状态与 Y 轴限位

## Y 轴机械限位

当前 `demo.py` 使用以下定义：

- 软件零点 `0°`：相机垂直于地面时的 Y 轴位置；
- 允许范围：相对软件零点 `-100°～+100°`；
- 禁止范围：上述区间之外的所有位置。

在圆周死区表达中，这等价于“以 180°为中心、宽 160°的禁止区”，因此命令行默认参数是：

```text
--y-dead-width 160
--y-dead-center 180
--y-dead-margin 0
```

例如请求 `--y 150` 时，程序只会下发 `+100°`。

## 状态参数地址

`motor_status.py` 中的 `read_motor_status()` 是独立状态读取函数。这里的参数地址是 F32C 返回帧第 3 字节的“反馈类型”，不是用于发送控制帧的电机 ID：

| 参数地址 | 状态 | 换算 |
|---|---|---|
| `0x00` | 实时速度 | RPM |
| `0x01` | 多圈累计角度 | 原始值 × 0.1° |
| `0x02` | 单圈机械角度 | 原始值 × 0.1° |
| `0x03` | 加速度 | 保留原始值 |
| `0x04` | 母线电压 | 原始值 × 0.01V |

默认运行时以 2Hz 查询速度、累计角度和母线电压：

```powershell
python demo.py --port COM5 manual --x 5 --y 10 --status-rate 2
```

查询 `0x00～0x04` 全部状态：

```powershell
python demo.py --port COM5 manual --x 5 --y 10 --status-rate 2 --status-all
```

关闭状态输出：

```powershell
python demo.py --port COM5 manual --x 5 --y 10 --status-rate 0
```

典型输出：

```text
STATUS X[motor=0x01 0x00=0rpm(0) 0x01=5deg(50) 0x04=12V(1200)] |
       Y[motor=0x02 0x00=0rpm(0) 0x01=10deg(100) 0x04=12V(1200)]
```

其中 `motor=0x01/0x02` 是响应电机地址；`0x00/0x01/0x04` 才是对应的状态参数地址。

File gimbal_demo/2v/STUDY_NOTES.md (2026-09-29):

# 附送资料研读结论

资料包共盘点到 1148 个文件：25 份 PDF、16 个 MP4、13 个 TXT、3 个 Markdown、197 个 C/H 源文件，以及驱动、固件、工程索引/编译产物、压缩包、DWG/STP/PNG 等。控制设计主要依据最新的两份 2026-07 手册和已展开/压缩工程中的位置、速度与绘图例程；安装、驱动、原理图和 K230 支架资料用于核对电气与机械边界。

## 直接影响代码的结论

- 云台级联默认使用 ID 1（底部 yaw/X）和 ID 2（上部 pitch/Y）。
- 串口为 TTL 3.3V、115200-8-N-1；帧头 `0x7A`、帧尾 `0x7B`，BCC 是校验位之前所有字节逐字节异或。
- 总线上每个完整帧之间至少间隔 1ms；代码使用 2ms。
- 推荐控制频率 100Hz，最大 200Hz。K230 示例取 50Hz，为推理留出余量。
- 频繁改变目标位置时，应采用多圈绝对位置直通模式 `0x0003`，而不是带 T 型规划的 `0x0001`。
- 多圈位置值是有符号 32 位大端整数，单位 0.1°；反馈总角度同样是有符号 32 位、0.1°。
- 电机上电后先等待约 1.5s，再按“使能 -> 模式 -> 速度 -> 位置”顺序控制。
- 为避免启动瞬间跳到电机上电零点，先读取两轴当前总角度，把当前物理姿态建立为软件零点。
- 资料中的 STM32F4 绘图例程也采用直通位置模式、软件零点、周期反馈、反馈超时与总线串行调度，和本 demo 的结构一致。

## 硬件与机械边界

- 电机主电源 8~15V，推荐 3S；额定电流约 0.4A，最大工作/堵转电流约 1.5A。
- 电机最大 1000RPM、最小 1RPM，14-bit 角度分辨率；多圈位置指令最小单位 0.1°。
- 所有接口禁止热插拔，电源反接可能永久损坏驱动板。
- 安装资料要求电机支架使用 M2.5x5 沉头螺丝；超过 5mm 可能锁坏电机。
- 随货手册给出的建议负载不超过 100g，且重心应尽量位于电机中心。
- 关于滑环最大电流，云台手册不同页存在 1A 与 1.5A 两种表述。工程上应按更保守的 1A 设计，并实测 K230 峰值电流；必要时让滑环只传信号、另行可靠供电。

## 资料中的易混淆点

- 单电机手册写默认 ID 为 2，但成套双轴云台的快速协议和例程明确使用 X=1、Y=2。本 demo 按成套云台配置；若反馈超时，应先断开级联并用上位机逐台核对 ID。
- 最新手册更新记录提到曾修正协议 ID，因此没有沿用旧视频或旧版手册中的地址示例。
- “Y 轴 120°死角”在需求中没有给出死角中心。本 demo 默认死角中心位于逻辑 180°（后方），形成连续安全区间 `-120°~+120°`；再加 2°边界后实际为 `-118°~+118°`。安装零位不同必须修改死角中心或重新建立软件零点。
- 视觉闭环只消费检测框中心。目标检测、目标 ID 保持、相机内参/畸变、相机与两轴的外参及运动提前量属于后续标定和算法层。

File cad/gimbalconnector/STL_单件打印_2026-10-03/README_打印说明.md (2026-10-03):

# 单件 STL 打印包

所有文件另存于本目录，原模型、已有 STL、Fusion 文件及项目说明均未修改。每个 STL 只包含一个独立且封闭的连通零件，以 mm 为单位；仅平移到 XY 居中、最低点 Z=0，没有缩放或旋转。导入切片软件后可分别旋转、排列和设置数量。最低点归零不代表已经选择最佳打印朝向，底座的下伸柱和四角固定立边仍需检查支撑。

## 目录选择

| 目录 | 用途 | STL 数量 |
|---|---|---|
| `01_V3_USB优化版/` | 外移、预留 USB 空间的当前版本 | 5 个正式部件 + 4 个试件 |
| `02_V2_原位置加强版/` | 保持原位置，增加底柱和侧向热铆销 | 5 个正式部件 + 4 个试件 |
| `03_V2_原版/` | 最初确认长边对齐的版本 | 4 个正式部件 + 4 个试件 |
| `04_V1_历史方向试作_未采用/` | 仅为完整保留早期单件导出，方向未采用 | 4 个正式部件 + 4 个试件 |

共 34 个单件 STL。建议从前三个目录中选择一版使用；V1 仅供历史参考。每版的间隙试装件单独放在 `试装件/` 中。

## 零件选择与数量

| 文件前缀 | 零件 | 打印数量 |
|---|---|---|
| `01_` | 摩擦快拆底座，一体底部热铆柱固定 | 1，与 `02_` 二选一 |
| `02_` | 摩擦快拆底座，M2 螺丝固定 | 1，与 `01_` 二选一 |
| `03_` | 相机快装板，中心 1/4 英寸金属螺丝固定 | 1，与 `04_` 二选一 |
| `04_` | 相机快装板，保留中心孔并增加四角螺丝固定立边 | 1，与 `03_` 二选一 |
| `05_` | 独立侧向热铆销，文件只有一颗 | **2 颗**，加强版和 USB 版使用 |

快拆板与底座之间通过打印燕尾和弹性肋摩擦固定。`01_`/`02_` 是底座与云台的两种固定方式，`03_`/`04_` 是相机与快装板的两种固定方式。

USB 版热铆组合示例：在 `01_V3_USB优化版/` 导入 `01_` 底座、`03_` 或 `04_` 相机板，再导入 `05_` 铆销并把数量设置为 2。M2 底座也保留侧向销孔。中心 1/4 英寸螺丝、M2 螺丝及相机四角螺丝为金属紧固件，不属于打印零件。

**底座底部热铆柱与底座一体成型，四角固定立边与相机板一体成型，因此分别保留在对应单件 STL 中。** 独立侧向热铆销已单独导出。将一体结构拆成分离零件需要增加连接结构，属于新的设计改动，本次导出保持原设计。

## 检查记录

`打印清单.csv` 列出每个文件的数量、用途、尺寸及来源。`单件网格验证.json` 记录每个零件的单一连通性、封闭性、退化面、尺寸及体积保持检查，并保存已有项目文件的 SHA-256 校验结果。`单件STL打印包.zip` 包含各版单件 STL、说明和检查记录，解压后使用。

打印朝向、支撑、螺丝长度与热铆装配步骤可参阅原项目 `README_快拆转接台.md` 和 `README_加强版与USB优化.md`。实际摩擦保持力与热铆强度仍需打印试装。

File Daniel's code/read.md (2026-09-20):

mainflat mainweb 和 mainweb2是能用的，mainweb里面有高度检测的功能，mainflat是烧录固定高度

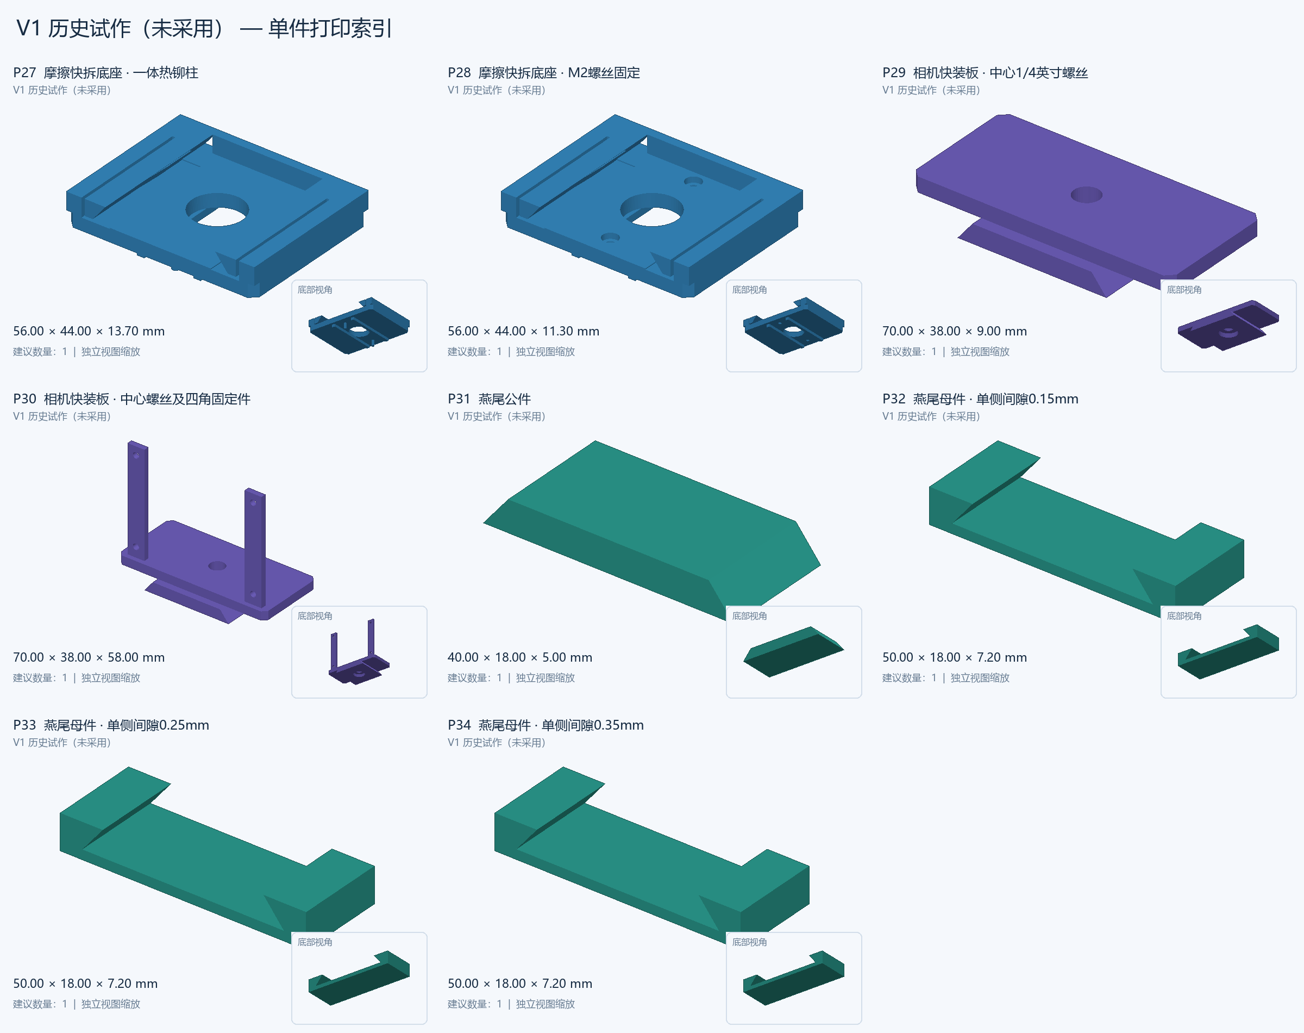
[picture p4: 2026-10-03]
cad/gimbalconnector/零件缩略图_2026-10-03/04_零件总览.png

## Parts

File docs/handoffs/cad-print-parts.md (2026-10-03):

# CAD 打印文件同步交接

- 日期：2026-10-03
- 分支：`cad/maixcam2-print-parts`
- 起点：`origin/main` @ `14b0fe4`
- 范围：`cad/` 中的相机快拆转接台、单件打印文件、缩略图及两版电机支架。

## 已完成

- 从本地 `gimbalconnector/` 复制模型、各版导出、脚本、说明和验证记录；保持文件内容和相对目录。
- `cad/motor_brackets/v1/` 保存原版电机支架和连接板；`v2/` 保存带 `2` 后缀的第二版两件 STL。
- `cad/README.md` 提供版本入口、GitHub 可直接显示的 PNG 缩略图总览和离线 HTML 索引。
- `cad/SYNC_MANIFEST.json` 记录 234 个复制文件的来源、目标、字节数和 SHA-256，逐一核对来源及复制结果。
- 单件打印包包含 34 个 STL；缩略图目录包含 34 张双视角图片和 4 张版本总览。原版和历史试作均保留。
- 只提交 CAD 目录及本交接文件；其他工作副本中的 MaixCAM、v3 云台代码和 Python 缓存不属于此提交。

## 验证与边界

- 所有复制文件哈希一致；本地原始文件没有改动。
- 原转接台验证报告随文件保存；本次另外核对单件文件、缩略图链接和索引相对路径。
- 两版电机支架为原样 STL 文件，不因上传而修改模型、推定兼容性或增加硬件验收结论。
- 没有打印、实机装配、USB 线缆弯曲或云台运动测试；没有启动电机。

## 接手

1. 获取此分支并读取 `cad/README.md`。
2. 选定一个转接台版本及对应底座/快装板；侧向铆销按需打印两颗。
3. 本地浏览器打开 `cad/gimbalconnector/零件缩略图_2026-10-03/零件索引.html`，或直接查看 README 的 PNG 总览。
4. 需要改模型时先阅读各版本设计说明和复建工具，保留已确认版本，再进行实际打印试装。

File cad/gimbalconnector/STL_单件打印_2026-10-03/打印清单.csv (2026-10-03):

STL文件 | 建议数量 | 用途 | X尺寸mm | Y尺寸mm | Z尺寸mm | 来源
01_V3_USB优化版/03_相机快装板_中心1-4英寸螺丝.stl | 1 | 相机板二选一 | 38.0 | 70.0 | 9.0 | output_v3_usb/camera_plate.stl
01_V3_USB优化版/04_相机快装板_中心螺丝及四角固定件.stl | 1 | 相机板二选一；立边与板一体成型 | 38.0 | 70.0 | 58.0 | output_v3_usb/camera_plate_four_screw.stl
01_V3_USB优化版/试装件/02_燕尾母件_单侧间隙0.15mm.stl | 1 | 可选间隙试装件 | 50.0 | 18.0 | 7.2 | output_v3_usb/fit_coupon_gap_0.15.stl
01_V3_USB优化版/试装件/03_燕尾母件_单侧间隙0.25mm.stl | 1 | 可选间隙试装件 | 50.0 | 18.0 | 7.2 | output_v3_usb/fit_coupon_gap_0.25.stl
01_V3_USB优化版/试装件/04_燕尾母件_单侧间隙0.35mm.stl | 1 | 可选间隙试装件 | 50.0 | 18.0 | 7.2 | output_v3_usb/fit_coupon_gap_0.35.stl
01_V3_USB优化版/试装件/01_燕尾公件.stl | 1 | 可选间隙试装件 | 40.0 | 18.0 | 5.0 | output_v3_usb/fit_coupon_male.stl
01_V3_USB优化版/01_摩擦快拆底座_一体热铆柱.stl | 1 | 底座二选一 | 44.0 | 80.15 | 22.7 | output_v3_usb/receiver_heat_stake.stl
01_V3_USB优化版/02_摩擦快拆底座_M2螺丝固定.stl | 1 | 底座二选一 | 44.0 | 80.15 | 19.3 | output_v3_usb/receiver_M2_bolt.stl
01_V3_USB优化版/05_独立侧向热铆销_单颗_打印2颗.stl | 2 | 加强版和USB版侧向两孔固定 | 5.5 | 5.5 | 11.0 | output_v3_usb/side_heat_rivet_print_2.stl
02_V2_原位置加强版/03_相机快装板_中心1-4英寸螺丝.stl | 1 | 相机板二选一 | 38.0 | 70.0 | 9.0 | output_v2_reinforced/camera_plate.stl
02_V2_原位置加强版/04_相机快装板_中心螺丝及四角固定件.stl | 1 | 相机板二选一；立边与板一体成型 | 38.0 | 70.0 | 58.0 | output_v2_reinforced/camera_plate_four_screw.stl
02_V2_原位置加强版/试装件/02_燕尾母件_单侧间隙0.15mm.stl | 1 | 可选间隙试装件 | 50.0 | 18.0 | 7.2 | output_v2_reinforced/fit_coupon_gap_0.15.stl
02_V2_原位置加强版/试装件/03_燕尾母件_单侧间隙0.25mm.stl | 1 | 可选间隙试装件 | 50.0 | 18.0 | 7.2 | output_v2_reinforced/fit_coupon_gap_0.25.stl
02_V2_原位置加强版/试装件/04_燕尾母件_单侧间隙0.35mm.stl | 1 | 可选间隙试装件 | 50.0 | 18.0 | 7.2 | output_v2_reinforced/fit_coupon_gap_0.35.stl
02_V2_原位置加强版/试装件/01_燕尾公件.stl | 1 | 可选间隙试装件 | 40.0 | 18.0 | 5.0 | output_v2_reinforced/fit_coupon_male.stl
02_V2_原位置加强版/01_摩擦快拆底座_一体热铆柱.stl | 1 | 底座二选一 | 44.0 | 73.0 | 17.7 | output_v2_reinforced/receiver_heat_stake.stl
02_V2_原位置加强版/02_摩擦快拆底座_M2螺丝固定.stl | 1 | 底座二选一 | 44.0 | 73.0 | 14.3 | output_v2_reinforced/receiver_M2_bolt.stl
02_V2_原位置加强版/05_独立侧向热铆销_单颗_打印2颗.stl | 2 | 加强版和USB版侧向两孔固定 | 5.5 | 5.5 | 11.0 | output_v2_reinforced/side_heat_rivet_print_2.stl
03_V2_原版/03_相机快装板_中心1-4英寸螺丝.stl | 1 | 相机板二选一 | 38.0 | 70.0 | 9.0 | output_v2/camera_plate.stl
03_V2_原版/04_相机快装板_中心螺丝及四角固定件.stl | 1 | 相机板二选一；立边与板一体成型 | 38.0 | 70.0 | 58.0 | output_v2/camera_plate_four_screw.stl
03_V2_原版/试装件/02_燕尾母件_单侧间隙0.15mm.stl | 1 | 可选间隙试装件 | 50.0 | 18.0 | 7.2 | output_v2/fit_coupon_gap_0.15.stl
03_V2_原版/试装件/03_燕尾母件_单侧间隙0.25mm.stl | 1 | 可选间隙试装件 | 50.0 | 18.0 | 7.2 | output_v2/fit_coupon_gap_0.25.stl
03_V2_原版/试装件/04_燕尾母件_单侧间隙0.35mm.stl | 1 | 可选间隙试装件 | 50.0 | 18.0 | 7.2 | output_v2/fit_coupon_gap_0.35.stl
03_V2_原版/试装件/01_燕尾公件.stl | 1 | 可选间隙试装件 | 40.0 | 18.0 | 5.0 | output_v2/fit_coupon_male.stl
03_V2_原版/01_摩擦快拆底座_一体热铆柱.stl | 1 | 底座二选一 | 44.0 | 56.0 | 16.7 | output_v2/receiver_heat_stake.stl
03_V2_原版/02_摩擦快拆底座_M2螺丝固定.stl | 1 | 底座二选一 | 44.0 | 56.0 | 14.3 | output_v2/receiver_M2_bolt.stl
04_V1_历史方向试作_未采用/03_相机快装板_中心1-4英寸螺丝.stl | 1 | 相机板二选一 | 70.0 | 38.0 | 9.0 | output_v1/camera_plate.stl
04_V1_历史方向试作_未采用/04_相机快装板_中心螺丝及四角固定件.stl | 1 | 相机板二选一；立边与板一体成型 | 70.0 | 38.0 | 58.0 | output_v1/camera_plate_four_screw.stl
04_V1_历史方向试作_未采用/试装件/02_燕尾母件_单侧间隙0.15mm.stl | 1 | 可选间隙试装件 | 50.0 | 18.0 | 7.2 | output_v1/fit_coupon_gap_0.15.stl
04_V1_历史方向试作_未采用/试装件/03_燕尾母件_单侧间隙0.25mm.stl | 1 | 可选间隙试装件 | 50.0 | 18.0 | 7.2 | output_v1/fit_coupon_gap_0.25.stl
04_V1_历史方向试作_未采用/试装件/04_燕尾母件_单侧间隙0.35mm.stl | 1 | 可选间隙试装件 | 50.0 | 18.0 | 7.2 | output_v1/fit_coupon_gap_0.35.stl
04_V1_历史方向试作_未采用/试装件/01_燕尾公件.stl | 1 | 可选间隙试装件 | 40.0 | 18.0 | 5.0 | output_v1/fit_coupon_male.stl
04_V1_历史方向试作_未采用/01_摩擦快拆底座_一体热铆柱.stl | 1 | 底座二选一 | 56.0 | 44.0 | 13.7 | output_v1/receiver_heat_stake.stl
04_V1_历史方向试作_未采用/02_摩擦快拆底座_M2螺丝固定.stl | 1 | 底座二选一 | 56.0 | 44.0 | 11.3 | output_v1/receiver_M2_bolt.stl

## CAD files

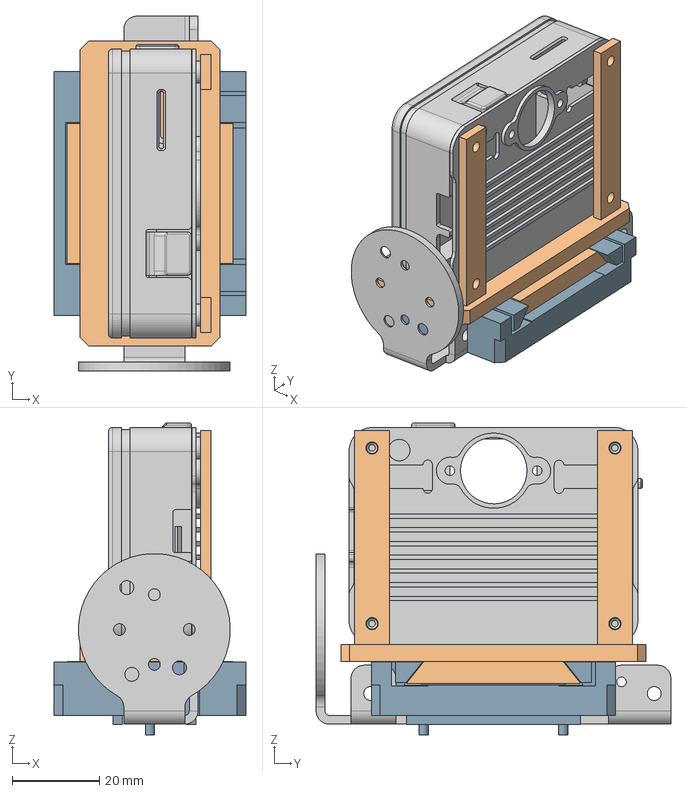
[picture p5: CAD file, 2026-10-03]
cad/gimbalconnector/output_v2/MaixCAM2_quick_release_assembly.step
44.0 x 81.3 x 71.5 mm

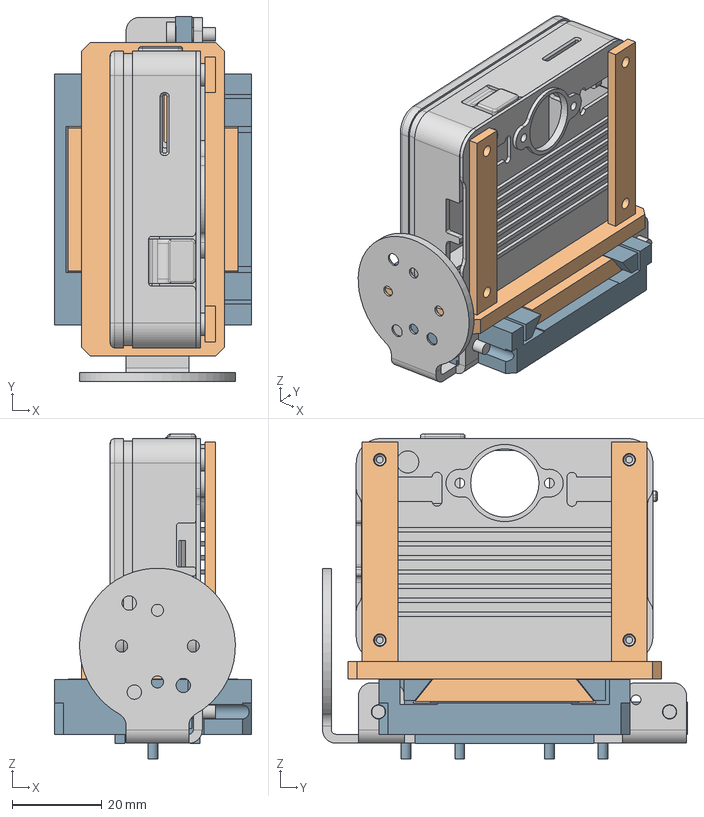
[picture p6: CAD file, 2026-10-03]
cad/gimbalconnector/output_v2_reinforced/MaixCAM2_quick_release_assembly.step
44.0 x 81.5 x 72.5 mm

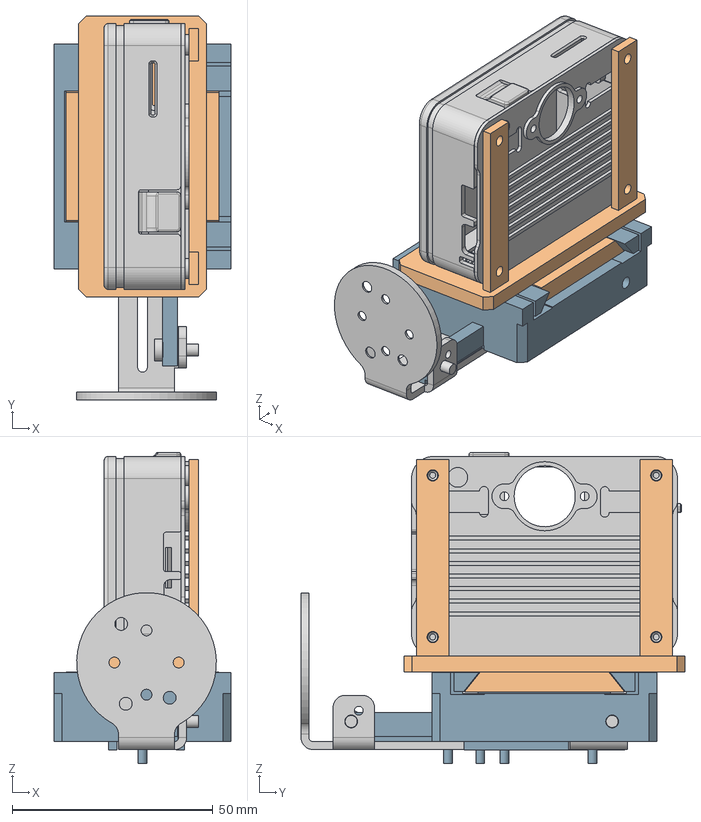
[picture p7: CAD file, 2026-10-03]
cad/gimbalconnector/output_v3_usb/MaixCAM2_quick_release_assembly.step
44.0 x 95.7 x 77.5 mm

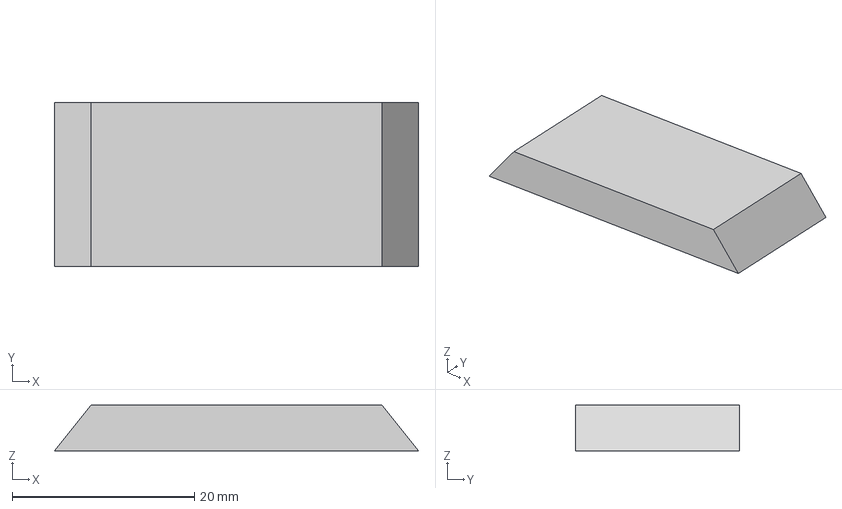
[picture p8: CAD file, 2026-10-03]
cad/gimbalconnector/output_v2/fit_coupon_male.step
40.0 x 18.0 x 5.00 mm

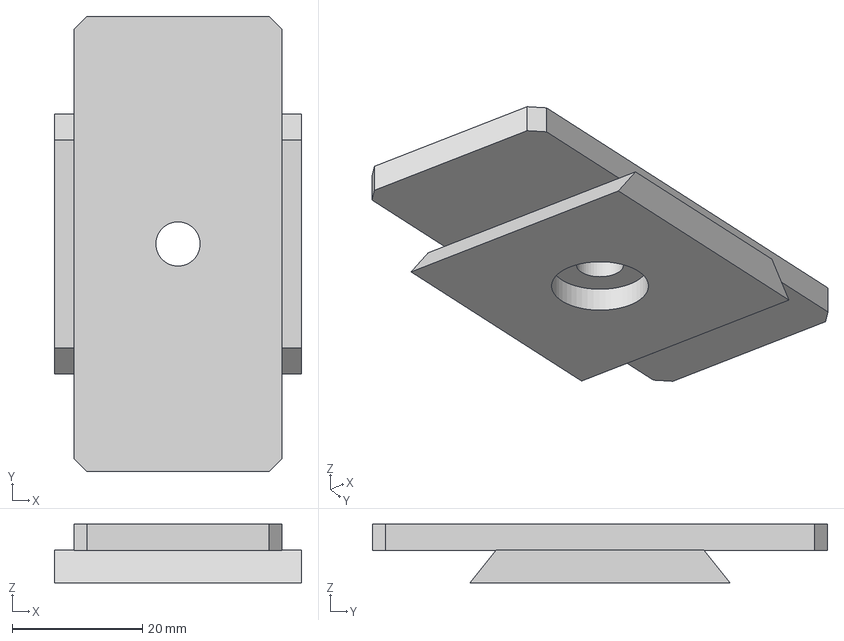
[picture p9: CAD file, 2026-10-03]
cad/gimbalconnector/output_v2_reinforced/camera_plate.step
38.0 x 70.0 x 9.00 mm

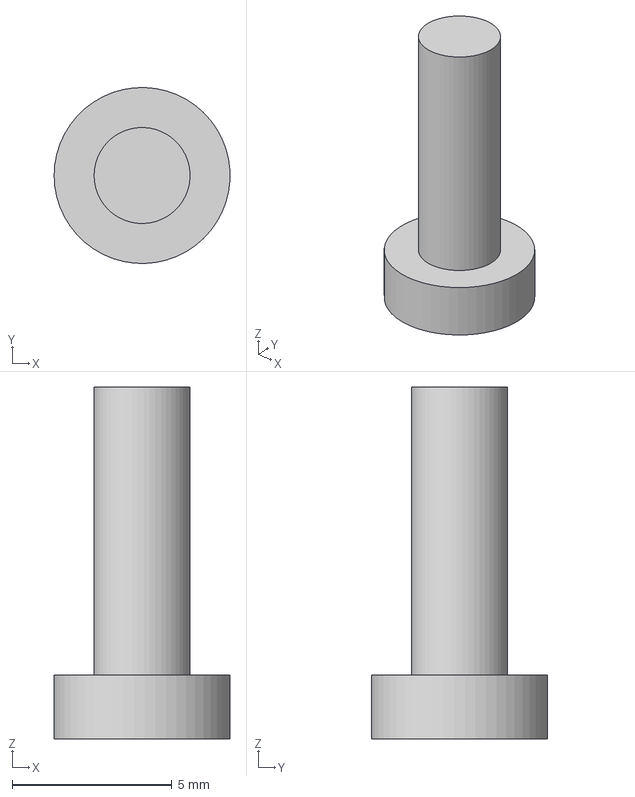
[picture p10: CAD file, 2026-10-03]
cad/gimbalconnector/output_v3_usb/side_heat_rivet_print_2.step
5.49 x 5.50 x 11.0 mm

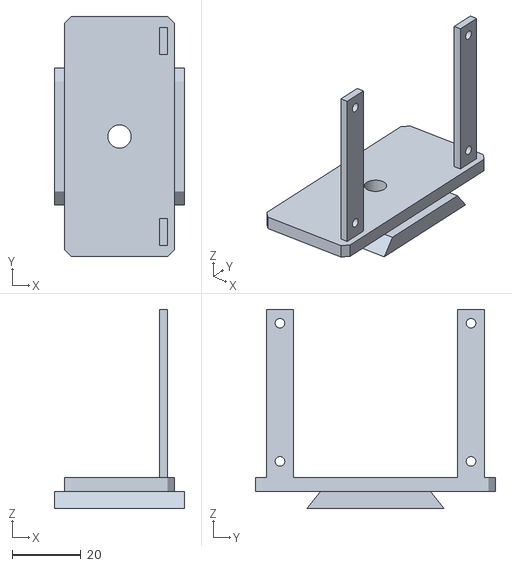
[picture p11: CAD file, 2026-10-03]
cad/gimbalconnector/STL_单件打印_2026-10-03/01_V3_USB优化版/04_相机快装板_中心螺丝及四角固定件.stl
38.0 x 70.0 x 58.0

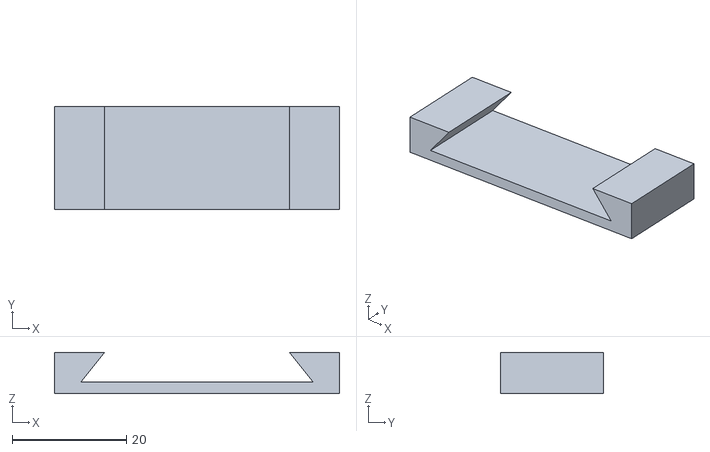
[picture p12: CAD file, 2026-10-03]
cad/gimbalconnector/STL_单件打印_2026-10-03/01_V3_USB优化版/试装件/02_燕尾母件_单侧间隙0.15mm.stl
50.0 x 18.0 x 7.20

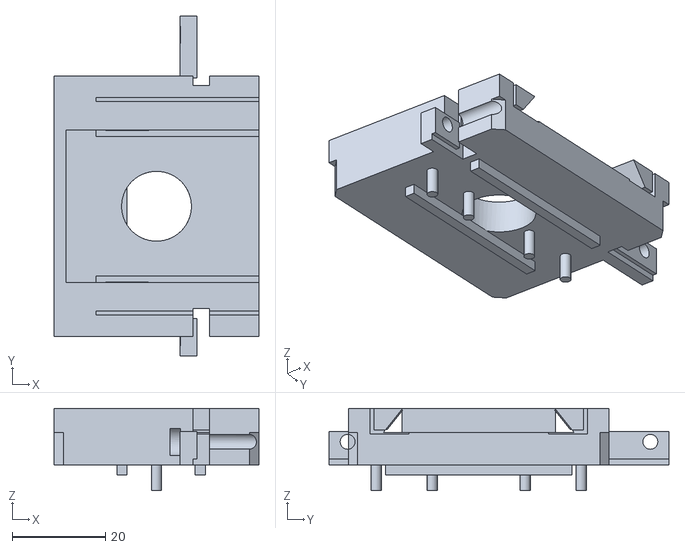
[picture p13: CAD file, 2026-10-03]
cad/gimbalconnector/STL_单件打印_2026-10-03/02_V2_原位置加强版/01_摩擦快拆底座_一体热铆柱.stl
44.0 x 73.0 x 17.7

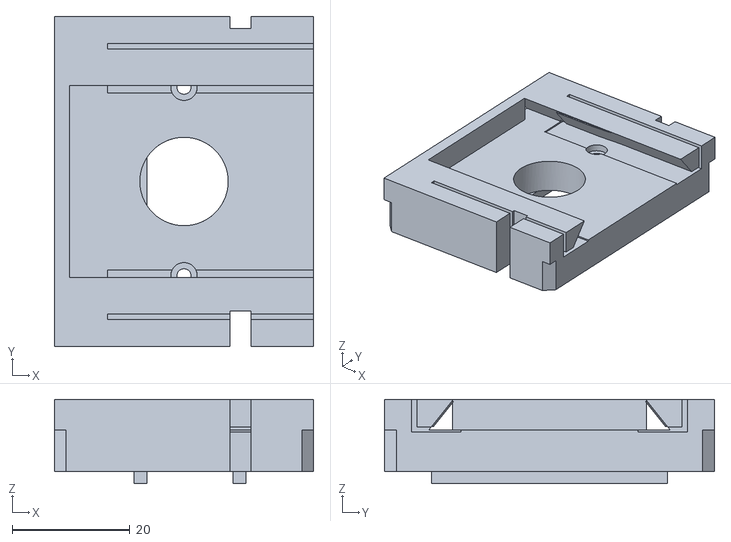
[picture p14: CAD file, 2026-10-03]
cad/gimbalconnector/STL_单件打印_2026-10-03/03_V2_原版/02_摩擦快拆底座_M2螺丝固定.stl
44.0 x 56.0 x 14.3

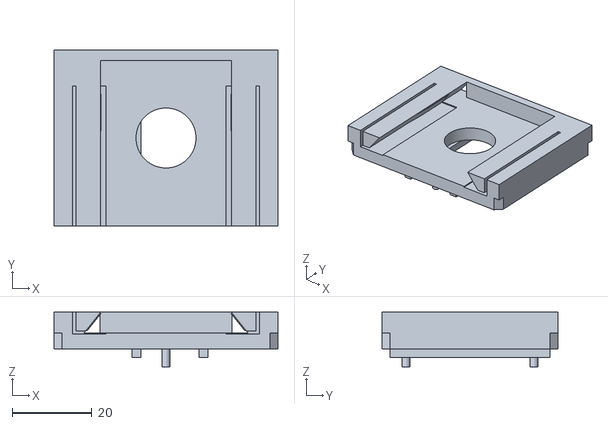
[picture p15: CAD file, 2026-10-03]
cad/gimbalconnector/STL_单件打印_2026-10-03/04_V1_历史方向试作_未采用/01_摩擦快拆底座_一体热铆柱.stl
56.0 x 44.0 x 13.7

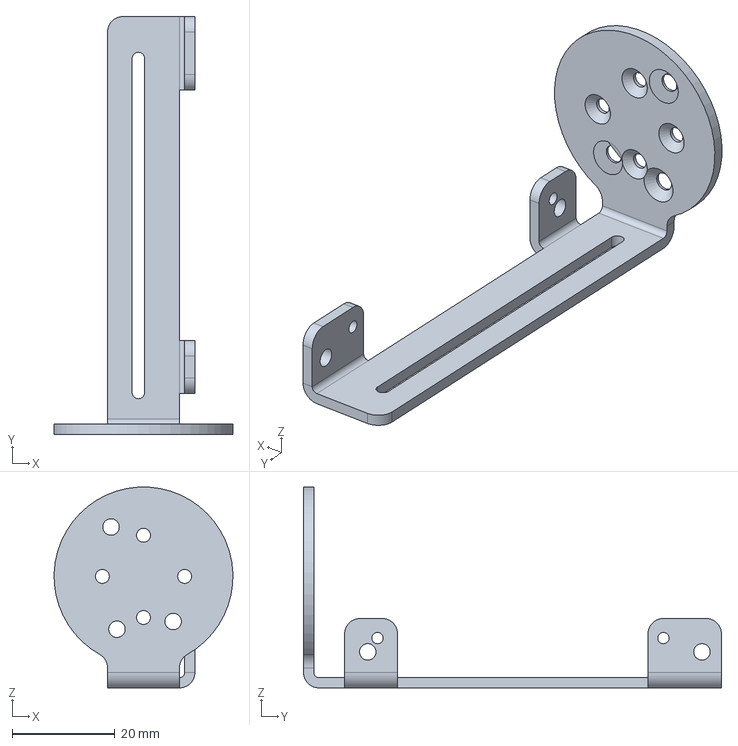
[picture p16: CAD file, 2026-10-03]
cad/gimbalconnector/云台连接件.step
34.8 x 81.3 x 39.0 mm

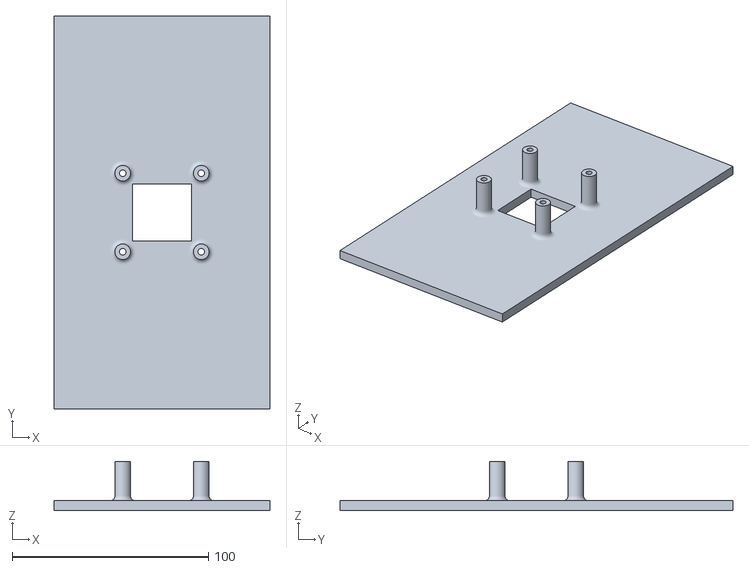
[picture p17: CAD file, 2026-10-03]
cad/motor_brackets/v2/电机支架2.stl
110.0 x 200.0 x 25.0

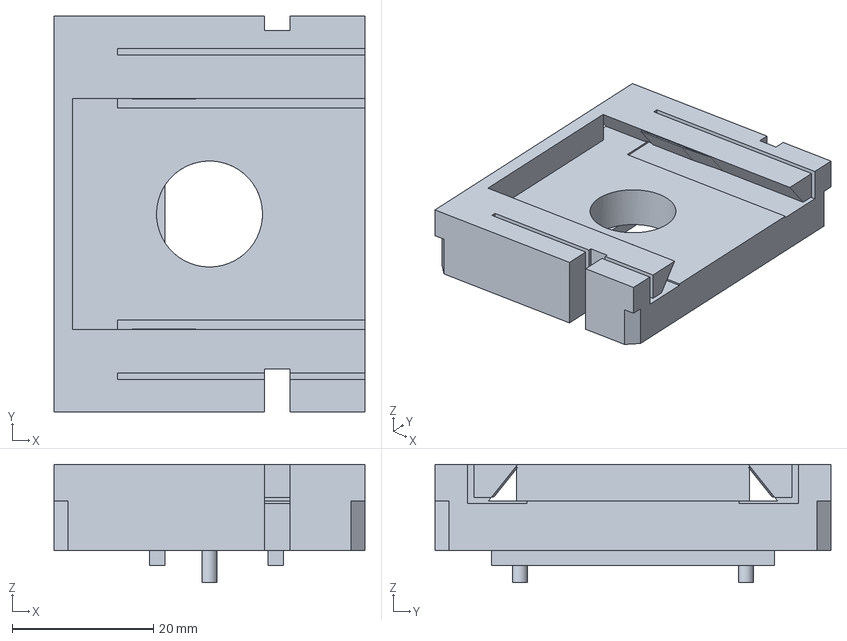
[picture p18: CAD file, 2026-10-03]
cad/gimbalconnector/output_v2/receiver_heat_stake.step
44.0 x 56.0 x 16.7 mm

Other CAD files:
cad/gimbalconnector/STL_单件打印_2026-10-03/03_V2_原版/试装件/01_燕尾公件.stl
cad/gimbalconnector/output_v2_reinforced/fit_coupon_gap_0.25.step
cad/gimbalconnector/STL_单件打印_2026-10-03/01_V3_USB优化版/01_摩擦快拆底座_一体热铆柱.stl
cad/gimbalconnector/STL_单件打印_2026-10-03/01_V3_USB优化版/02_摩擦快拆底座_M2螺丝固定.stl
cad/gimbalconnector/STL_单件打印_2026-10-03/01_V3_USB优化版/03_相机快装板_中心1-4英寸螺丝.stl
cad/gimbalconnector/STL_单件打印_2026-10-03/01_V3_USB优化版/05_独立侧向热铆销_单颗_打印2颗.stl
cad/gimbalconnector/STL_单件打印_2026-10-03/01_V3_USB优化版/试装件/01_燕尾公件.stl
cad/gimbalconnector/STL_单件打印_2026-10-03/01_V3_USB优化版/试装件/03_燕尾母件_单侧间隙0.25mm.stl
cad/gimbalconnector/STL_单件打印_2026-10-03/01_V3_USB优化版/试装件/04_燕尾母件_单侧间隙0.35mm.stl
cad/gimbalconnector/STL_单件打印_2026-10-03/02_V2_原位置加强版/02_摩擦快拆底座_M2螺丝固定.stl
cad/gimbalconnector/STL_单件打印_2026-10-03/02_V2_原位置加强版/03_相机快装板_中心1-4英寸螺丝.stl
cad/gimbalconnector/STL_单件打印_2026-10-03/02_V2_原位置加强版/04_相机快装板_中心螺丝及四角固定件.stl
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

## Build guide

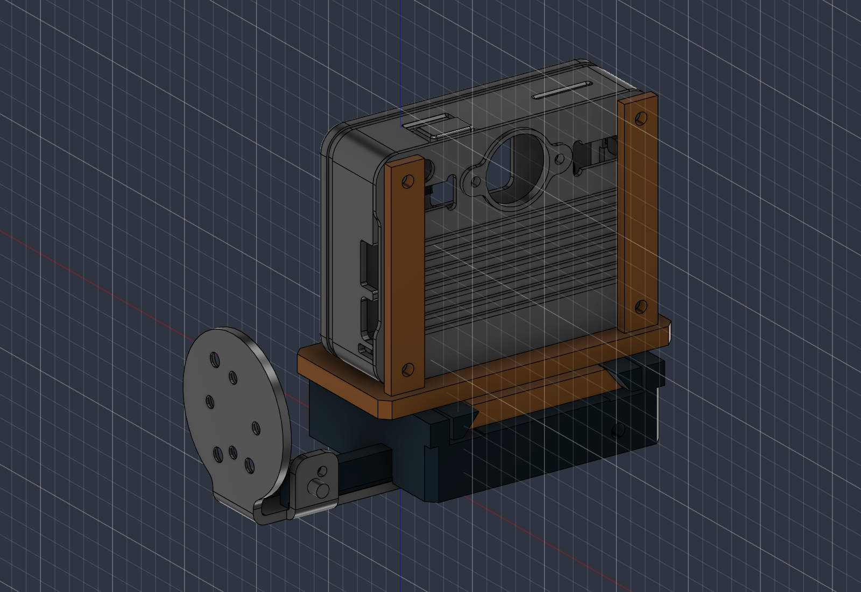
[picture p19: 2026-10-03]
cad/gimbalconnector/output_v3_usb/assembly_preview.png

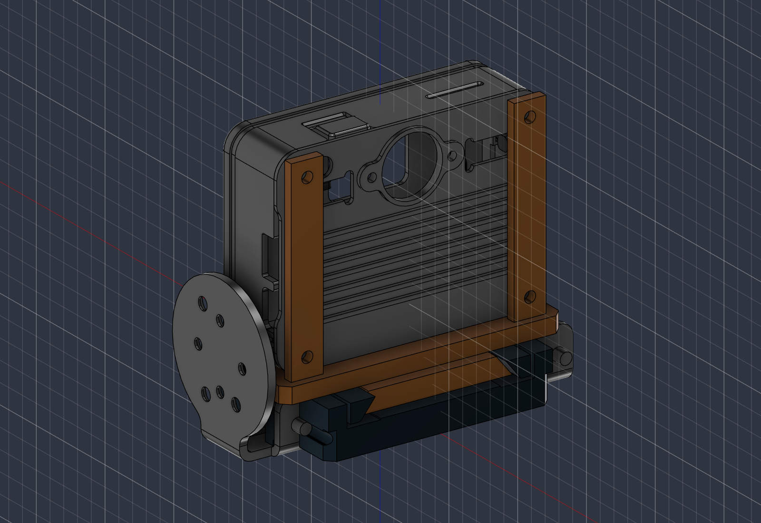
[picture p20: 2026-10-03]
cad/gimbalconnector/output_v2_reinforced/assembly_preview.png

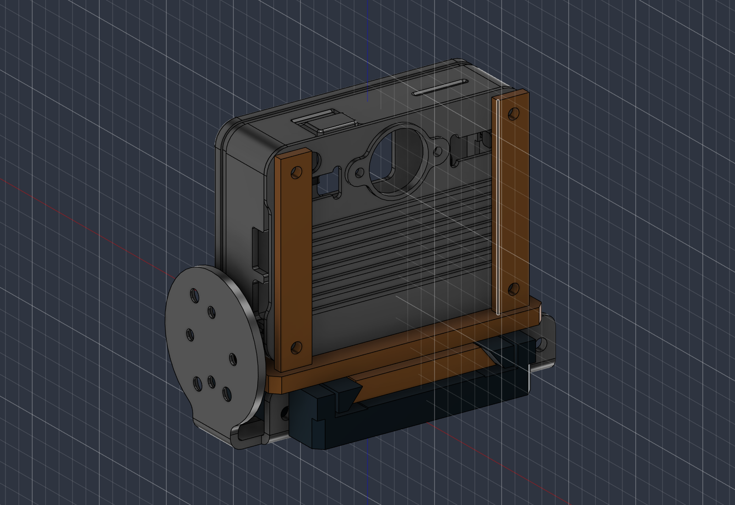
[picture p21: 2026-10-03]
cad/gimbalconnector/output_v2/assembly_preview.png

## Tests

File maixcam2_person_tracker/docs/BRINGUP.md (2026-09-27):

# Hardware Bring-Up Procedure

This procedure deliberately separates visual validation from motor activation. Keep people, cables, tools, and hard obstacles outside the gimbal travel envelope.

## 1. Verify power with all devices disconnected

1. Confirm the motor supply is within 8-15 V.
2. Confirm the MaixCAM 2 regulator produces a stable 5 V under load.
3. Confirm the two supplies share signal ground only where intended.
4. Confirm polarity before connecting either device.
5. Do not connect or disconnect an F32C interface while powered.

## 2. Verify TTL wiring

1. Connect MaixCAM 2 A21/UART4_TX to the gimbal RX line.
2. Connect MaixCAM 2 A22/UART4_RX to the gimbal TX line.
3. Connect grounds.
4. Confirm the signals are 3.3 V TTL.
5. Confirm pan motor ID `1` and tilt motor ID `2` using the vendor tool or known configuration.

## 3. Run vision-only mode

Keep `GimbalConfig.enabled = False`.

1. Place one person in view.
2. Run `main.py`.
3. Confirm a green box follows the person.
4. Confirm the mode reaches `TRACK` after three valid frames.
5. Briefly hide the person and confirm `COAST`, followed by `SEARCH` if the person stays hidden.
6. Confirm the yellow predicted marker continues through a short occlusion.
7. Inspect `/root/logs/person_tracker.csv`.

Do not continue if detections are unstable or the application reports an unexpected target angle sign.

## 4. Establish mechanical zero and limits

With motor power removed, place the camera at the intended neutral forward position.

1. Determine the F32C total-angle reading at neutral for each axis.
2. Set `zero_offset_deg` so the application's logical pose reads approximately `(0, 0)` at neutral.
3. Determine conservative pan and tilt travel limits that leave clearance before cables, hard stops, and structural interference.
4. Enter those limits in `minimum_deg` and `maximum_deg`.
5. Keep initial maximum rates below 20 deg/s if the axis direction has not yet been confirmed.

Do not issue the F32C persistent zero-setting command during normal application startup. Treat zero as calibration data in `config.py` until the complete mechanism has been validated.

## 5. Verify one axis at a time

The application currently initializes both motors when gimbal output is enabled. For initial bench verification, mechanically support the payload and temporarily set both axes to narrow limits around zero.

1. Set pan limits to approximately `-5` and `+5` degrees.
2. Set tilt limits to approximately `-3` and `+3` degrees.
3. Set maximum rates and accelerations to conservative values.
4. Set `GimbalConfig.enabled = True`.
5. Start the application with the person centered.
6. Move slowly to the image right. If the camera turns away from the person, stop immediately and reverse the pan `motor_sign` or camera `pan_pixel_sign` after determining which coordinate is wrong.
7. Repeat vertically and correct the tilt signs.

Never diagnose an incorrect sign by allowing the gimbal to run into a limit.

## 6. Expand the motion envelope

After direction and zero are correct:

1. Increase limits in small steps while checking cable clearance.
2. Increase maximum rate and acceleration gradually.
3. Tune F32C internal PID using the vendor procedure if the installed payload oscillates or overshoots.
4. Increase the software command rate only after UART feedback remains reliable.
5. Validate normal exit, application exception, feedback disconnection, and power cycling.

## 7. Closed-loop person test

1. Start with one person, uniform lighting, and a clear background.
2. Walk slowly across the field of view.
3. Confirm the target remains near the image center without sustained oscillation.
4. Add a second person and confirm the tracker does not jump when the locked person remains inside the association gate.
5. Occlude the target for 0.2-0.4 seconds and verify successful coast and reacquisition.
6. Extend the occlusion until the system enters local search.
7. Review CSV data for bearing rate, covariance growth, gimbal command, and state transitions.

## 8. Acceptance criteria for Stage 1

- Stable person lock without continuous gimbal oscillation.
- Correct pan and tilt response in every image quadrant.
- No command beyond configured software limits.
- Recovery from a 0.3 second person occlusion under a predictable walking motion.
- Transition to `FAULT` when both motor angles are not received within the configured timeout.
- Normal stop behavior matches the configured hold/disable policy.
- A usable telemetry record exists for every tuning run.

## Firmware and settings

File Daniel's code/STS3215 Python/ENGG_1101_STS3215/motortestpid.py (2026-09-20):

#!/usr/bin/env python
# -*- coding: utf-8 -*-
"""
ST3215 双轴云台控制 - 完整 PID 版（0~180°）
新增功能：
1. 每个轴独立 PID 控制器
2. GUI 中加入 Kp / Ki / Kd 调节滑块（实时生效）
3. 每个轴独立 “启用 PID” 开关
4. 实时读取当前角度并显示
5. PID 模式下：滑块/输入框设置的是【目标角度】，PID 自动驱动电机到达目标
6. 手动模式下：直接控制（和之前一样）
"""

import sys
import time
import tkinter as tk
from tkinter import ttk, messagebox

# ================== 添加 SDK 路径 ==================
sys.path.append("..")
from scservo_sdk import *

# ================== 配置（请修改这里） ==================
SERVO_ID_1 = 2          # ← 改成你的实际电机 ID
SERVO_ID_2 = 3
BAUDRATE   = 115200
DEVICENAME = 'COM5'     # ← 改成你的实际 COM 口

MOVING_SPEED = 2000
MOVING_ACC   = 30

MIN_ANGLE = 0
MAX_ANGLE = 180
DEFAULT_ANGLE = 90

# ================== PID 控制器类 ==================
class PIDController:
    def __init__(self, kp=1.2, ki=0.02, kd=0.4):
        self.kp = kp
        self.ki = ki
        self.kd = kd
        self.prev_error = 0.0
        self.integral = 0.0

    def compute(self, error, dt=0.05):
        """计算 PID 输出（角度增量）"""
        self.integral += error * dt
        derivative = (error - self.prev_error) / dt if dt > 0 else 0
        output = self.kp * error + self.ki * self.integral + self.kd * derivative
        self.prev_error = error
        return output   # 返回角度增量（度）

    def reset(self):
        self.prev_error = 0.0
        self.integral = 0.0

def angle_to_pos(angle):
    return int((angle % 360) * 4096 / 360)

def pos_to_angle(pos):
    return round((pos % 4096) * 360 / 4096, 1)

# ================== 初始化串口 ==================
portHandler = PortHandler(DEVICENAME)
packetHandler = sms_sts(portHandler)

if not portHandler.openPort():
    messagebox.showerror("错误", f"无法打开串口 {DEVICENAME}")
    sys.exit(1)
if not portHandler.setBaudRate(BAUDRATE):
    messagebox.showerror("错误", "无法设置波特率")
    portHandler.closePort()
    sys.exit(1)

print("串口初始化成功")

# ================== PID 实例 ==================
pid1 = PIDController(kp=1.2, ki=0.02, kd=0.4)
pid2 = PIDController(kp=1.2, ki=0.02, kd=0.4)

# ================== 目标角度 & 防抖 ==================
target_angle = {SERVO_ID_1: DEFAULT_ANGLE, SERVO_ID_2: DEFAULT_ANGLE}
last_sent_pos = {SERVO_ID_1: angle_to_pos(DEFAULT_ANGLE), SERVO_ID_2: angle_to_pos(DEFAULT_ANGLE)}

def read_current_angle(servo_id):
    """读取电机当前位置"""
    try:
        pos, speed, comm_result, error = packetHandler.ReadPosSpeed(servo_id)
        if comm_result == COMM_SUCCESS and error == 0:
            return pos_to_angle(pos)
        return None
    except:
        return None

def set_servo_position(servo_id, position):
    """直接发送位置（防抖）"""
    global last_sent_pos
    if abs(position - last_sent_pos.get(servo_id, 0)) >= 5:
        comm_result, error = packetHandler.WritePosEx(servo_id, position, MOVING_SPEED, MOVING_ACC)
        if comm_result == COMM_SUCCESS and error == 0:
            last_sent_pos[servo_id] = position
            # print(f"Servo {servo_id} → {pos_to_angle(position):.1f}°")
        time.sleep(0.05)

# ================== GUI ==================
class ServoGUI:
    def __init__(self, root):
        self.root = root
        self.root.title("ST3215 双轴云台 + PID 控制（0~180°）")
        self.root.geometry("820x680")

        # 每个轴的 PID 启用状态
        self.pid_enabled = {SERVO_ID_1: tk.BooleanVar(value=False),
                            SERVO_ID_2: tk.BooleanVar(value=False)}

        # PID 参数变量
        self.pid_vars = {
            SERVO_ID_1: {
                "kp": tk.DoubleVar(value=1.2),
                "ki": tk.DoubleVar(value=0.02),
                "kd": tk.DoubleVar(value=0.4)
            },
            SERVO_ID_2: {
                "kp": tk.DoubleVar(value=1.2),
                "ki": tk.DoubleVar(value=0.02),
                "kd": tk.DoubleVar(value=0.4)
            }
        }

        self.create_servo_panel(SERVO_ID_1, "Servo 1 - 俯仰轴", 0)
        self.create_servo_panel(SERVO_ID_2, "Servo 2 - 横滚轴", 1)

        # 底部全局按钮
        btn_frame = ttk.Frame(root)
        btn_frame.grid(row=2, column=0, columnspan=2, pady=15)
        ttk.Button(btn_frame, text="两轴回到中位 90°", command=self.go_to_middle).pack(side=tk.LEFT, padx=10)
        ttk.Button(btn_frame, text="重置两个 PID", command=self.reset_pids).pack(side=tk.LEFT, padx=10)
        ttk.Button(btn_frame, text="关闭程序", command=self.on_closing).pack(side=tk.LEFT, padx=10)

        # 启动 PID 循环（每 50ms 执行一次）
        self.pid_loop()

        self.go_to_middle()

    def create_servo_panel(self, servo_id, title, row):
        frame = ttk.LabelFrame(self.root, text=title, padding=15)
        frame.grid(row=row, column=0, columnspan=2, padx=20, pady=15, sticky="ew")

        # === 目标角度控制 ===
        ttk.Label(frame, text="目标角度 (0° ~ 180°):").grid(row=0, column=0, sticky="w", pady=5)
        self.target_scale = ttk.Scale(frame, from_=MIN_ANGLE, to=MAX_ANGLE, orient=tk.HORIZONTAL,
                                      length=500, command=lambda v, sid=servo_id: self.on_target_change(sid, float(v)))
        self.target_scale.grid(row=1, column=0, columnspan=2, pady=5, sticky="ew")
        self.target_scale.set(DEFAULT_ANGLE)

        self.target_entry = ttk.Entry(frame, width=12, font=("Arial", 11))
        self.target_entry.grid(row=1, column=2, padx=10)
        self.target_entry.insert(0, str(DEFAULT_ANGLE))
        self.target_entry.bind("<Return>", lambda e, sid=servo_id: self.on_target_entry(sid))

        ttk.Button(frame, text="设置目标", command=lambda sid=servo_id: self.on_target_entry(sid)).grid(row=1, column=3, padx=5)

        # 当前角度显示
        ttk.Label(frame, text="当前角度:").grid(row=2, column=0, sticky="w", pady=8)
        self.current_label = ttk.Label(frame, text="--- °", font=("Arial", 12, "bold"), foreground="blue")
        self.current_label.grid(row=2, column=1, sticky="w", pady=8)

        # === PID 调节区 ===
        pid_frame = ttk.LabelFrame(frame, text="PID 参数调节", padding=10)
        pid_frame.grid(row=3, column=0, columnspan=4, pady=15, sticky="ew")

        ttk.Label(pid_frame, text="Kp:").grid(row=0, column=0, sticky="w")
        kp_scale = ttk.Scale(pid_frame, from_=0.0, to=5.0, orient=tk.HORIZONTAL, length=180,
                             variable=self.pid_vars[servo_id]["kp"],
                             command=lambda v, sid=servo_id: self.update_pid_params(sid))
        kp_scale.grid(row=0, column=1, padx=5)
        self.kp_val = ttk.Label(pid_frame, text="1.20")
        self.kp_val.grid(row=0, column=2)

        ttk.Label(pid_frame, text="Ki:").grid(row=1, column=0, sticky="w")
        ki_scale = ttk.Scale(pid_frame, from_=0.0, to=0.5, orient=tk.HORIZONTAL, length=180,
                             variable=self.pid_vars[servo_id]["ki"],
                             command=lambda v, sid=servo_id: self.update_pid_params(sid))
        ki_scale.grid(row=1, column=1, padx=5)
        self.ki_val = ttk.Label(pid_frame, text="0.02")
        self.ki_val.grid(row=1, column=2)

        ttk.Label(pid_frame, text="Kd:").grid(row=2, column=0, sticky="w")
        kd_scale = ttk.Scale(pid_frame, from_=0.0, to=3.0, orient=tk.HORIZONTAL, length=180,
                             variable=self.pid_vars[servo_id]["kd"],
                             command=lambda v, sid=servo_id: self.update_pid_params(sid))
        kd_scale.grid(row=2, column=1, padx=5)
        self.kd_val = ttk.Label(pid_frame, text="0.40")
        self.kd_val.grid(row=2, column=2)

        # 启用 PID 开关
        ttk.Checkbutton(pid_frame, text="启用 PID 控制（自动跟踪目标）", variable=self.pid_enabled[servo_id],
                        command=lambda sid=servo_id: self.toggle_pid(sid)).grid(row=3, column=0, columnspan=3, pady=8)

        # 保存引用
        if servo_id == SERVO_ID_1:
            self.panel1 = frame
            self.current_label1 = self.current_label
            self.target_scale1 = self.target_scale
            self.target_entry1 = self.target_entry
        else:
            self.panel2 = frame
            self.current_label2 = self.current_label
            self.target_scale2 = self.target_scale
            self.target_entry2 = self.target_entry

    def update_pid_params(self, servo_id):
        """滑块改变时实时更新 PID 参数"""
        p = self.pid_vars[servo_id]
        if servo_id == SERVO_ID_1:
            pid1.kp = p["kp"].get()
            pid1.ki = p["ki"].get()
            pid1.kd = p["kd"].get()
            # 更新显示值
            self.kp_val.config(text=f"{pid1.kp:.2f}")
            self.ki_val.config(text=f"{pid1.ki:.3f}")
            self.kd_val.config(text=f"{pid1.kd:.2f}")
        else:
            pid2.kp = p["kp"].get()
            pid2.ki = p["ki"].get()
            pid2.kd = p["kd"].get()
            self.kp_val.config(text=f"{pid2.kp:.2f}")
            self.ki_val.config(text=f"{pid2.ki:.3f}")
            self.kd_val.config(text=f"{pid2.kd:.2f}")

    def toggle_pid(self, servo_id):
        """切换 PID 开关时重置积分"""
        if servo_id == SERVO_ID_1:
            pid1.reset()
        else:
            pid2.reset()

    def on_target_change(self, servo_id, angle):
        """目标滑块移动"""
        target_angle[servo_id] = angle
        # 更新输入框
        if servo_id == SERVO_ID_1:
            self.target_entry1.delete(0, tk.END)
            self.target_entry1.insert(0, f"{angle:.1f}")
        else:
            self.target_entry2.delete(0, tk.END)
            self.target_entry2.insert(0, f"{angle:.1f}")

    def on_target_entry(self, servo_id):
        """输入框设置目标"""
        try:
            angle = float(self.target_entry1.get() if servo_id == SERVO_ID_1 else self.target_entry2.get())
            if MIN_ANGLE <= angle <= MAX_ANGLE:
                target_angle[servo_id] = angle
                if servo_id == SERVO_ID_1:
                    self.target_scale1.set(angle)
                else:
                    self.target_scale2.set(angle)
            else:
                messagebox.showwarning("范围错误", f"角度必须在 {MIN_ANGLE}~{MAX_ANGLE} 之间")
        except ValueError:
            messagebox.showerror("输入错误", "请输入有效的数字")

    def pid_loop(self):
        """每 50ms 执行一次 PID 计算 + 读取当前角度"""
        for sid in [SERVO_ID_1, SERVO_ID_2]:
            current = read_current_angle(sid)
            if current is not None:
                # 更新界面当前角度显示
                if sid == SERVO_ID_1:
                    self.current_label1.config(text=f"{current:.1f}°")
                else:
                    self.current_label2.config(text=f"{current:.1f}°")

                # 如果启用 PID，则进行控制
                if self.pid_enabled[sid].get():
                    error = target_angle[sid] - current
                    if sid == SERVO_ID_1:
                        delta = pid1.compute(error)
                        new_angle = current + delta
                    else:
                        delta = pid2.compute(error)
                        new_angle = current + delta

                    # 限制范围
                    new_angle = max(MIN_ANGLE, min(MAX_ANGLE, new_angle))
                    pos = angle_to_pos(new_angle)
                    set_servo_position(sid, pos)

        # 定时循环
        self.root.after(50, self.pid_loop)

    def go_to_middle(self):
        for sid in [SERVO_ID_1, SERVO_ID_2]:
            target_angle[sid] = DEFAULT_ANGLE
            if sid == SERVO_ID_1:
                self.target_scale1.set(DEFAULT_ANGLE)
                self.target_entry1.delete(0, tk.END)
                self.target_entry1.insert(0, str(DEFAULT_ANGLE))
            else:
                self.target_scale2.set(DEFAULT_ANGLE)
                self.target_entry2.delete(0, tk.END)
                self.target_entry2.insert(0, str(DEFAULT_ANGLE))
            set_servo_position(sid, angle_to_pos(DEFAULT_ANGLE))

    def reset_pids(self):
        pid1.reset()
        pid2.reset()
        messagebox.showinfo("PID 重置", "两个 PID 积分与历史误差已清零")

    def on_closing(self):
        if messagebox.askokcancel("退出", "确定关闭程序并关闭串口？"):
            portHandler.closePort()
            self.root.destroy()

# ================== 启动 ==================
if __name__ == "__main__":
    root = tk.Tk()
    app = ServoGUI(root)
    root.protocol("WM_DELETE_WINDOW", app.on_closing)
    root.mainloop()
    portHandler.closePort()
    print("串口已关闭")

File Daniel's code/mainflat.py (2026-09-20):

import cv2
import numpy as np
import time
import sys
import os
import threading
from collections import defaultdict, deque
from object_detection import ObjectDetection
from filterpy.kalman import KalmanFilter
from height_sensor import HeightSensor

# ================= 树莓派极致性能优化 =================
os.environ["OMP_NUM_THREADS"] = "2"
os.environ["MKL_NUM_THREADS"] = "2"
os.environ["OPENBLAS_NUM_THREADS"] = "2"
import torch
torch.set_num_threads(2)
torch.set_grad_enabled(False)
# =====================================================

# ================= 尝试导入电机 SDK =================
SDK_AVAILABLE = False
try:
    sys.path.append("..")
    from scservo_sdk import *
    SDK_AVAILABLE = True
except ImportError:
    print("Warning: scservo_sdk not found, running in simulation mode")
# =====================================================

# ================= 全局配置 =================
VIDEO_SOURCE = 6
IMG_W, IMG_H = 1920, 1080
YOLO_IMGSZ = 316          # Pi 甜点分辨率（兼顾精度与帧率）
FX_APPROX = 800
CONF_THRESHOLD = 0.4
TRACKER_TYPE = "bytetrack" # ByteTrack 比 BoT-SORT 快 2~3 倍
LOST_TIMEOUT = 2.0
DEVICENAME = 'COM5'
BAUDRATE = 115200
SERVO_PITCH = 1
SERVO_OTHER = 2
MIN_ANGLE, MAX_ANGLE = 0, 180
DEFAULT_ANGLE = 90
GIMBAL_MODE = "PITCH_ROLL"

# 🔑 防抖专用参数（增大死区 + 降低增益 + 增强平滑 + 限速）
DEADZONE_X = 65           # 🔺 横向死区：误差<65px 电机静止
DEADZONE_Y = 35           # 🔺 纵向死区：误差<35px 电机静止
GAIN_X  = 0.65          # 🔻 横向增益：响应更温和
GAIN_Y  = 0.4            # 🔻 纵向增益：克服重力但不过冲
EMA_X   = 0.08            # 🔻 横向平滑：重阻尼滤高频
EMA_Y   = 0.10            # 🔻 纵向平滑
STEP_X  = 2             # 🔻 横向单帧最大转角（度）
STEP_Y  = 2             # 🔻 纵向单帧最大转角（度）
DIR_X = 1; DIR_Y = -1
HEIGHT_INTERVAL = 0.2     # 5Hz 节流
# ============================================

# ================= 摄像头多线程 =================
class CameraStream:
    def __init__(self, src):
        self.cap = cv2.VideoCapture(src, cv2.CAP_V4L2)
        self.cap.set(cv2.CAP_PROP_BUFFERSIZE, 1)
        self.cap.set(cv2.CAP_PROP_FRAME_WIDTH, IMG_W)
        self.cap.set(cv2.CAP_PROP_FRAME_HEIGHT, IMG_H)
        self.ret, self.frame = self.cap.read()
        self.lock = threading.Lock()
        self.running = True
        threading.Thread(target=self._update, daemon=True).start()

    def _update(self):
        while self.running:
            ret, frame = self.cap.read()
            if ret:
                with self.lock:
                    self.ret, self.frame = ret, frame

    def read(self):
        with self.lock:
            return self.ret, self.frame.copy()

    def release(self):
        self.running = False
        self.cap.release()

# ================= 异步电机控制器 =================
class AsyncMotorController:
    def __init__(self, active, port_handler, packet_handler, p_id, o_id):
        self.active = active
        self.ph = port_handler
        self.pkt = packet_handler
        self.p_id, self.o_id = p_id, o_id
        self.target_pitch = DEFAULT_ANGLE
        self.target_other = DEFAULT_ANGLE
        self.cmd_queue = []
        self.lock = threading.Lock()
        if active:
            threading.Thread(target=self._worker, daemon=True).start()

    def _worker(self):
        while True:
            with self.lock:
                if self.cmd_queue:
                    sid, pos = self.cmd_queue.pop(0)
            if 'sid' in locals():
                try:
                    self.pkt.WritePosEx(sid, pos, 2500, 60)
                except: pass
            time.sleep(0.005)

    def set_target_angles(self, pitch, other):
        self.target_pitch = np.clip(pitch, MIN_ANGLE, MAX_ANGLE)
        self.target_other = np.clip(other, MIN_ANGLE, MAX_ANGLE)
        if self.active:
            with self.lock:
                self.cmd_queue.append((self.p_id, int((self.target_pitch % 360) * 4096 / 360)))
                self.cmd_queue.append((self.o_id, int((self.target_other % 360) * 4096 / 360)))

    def reset(self):
        self.set_target_angles(DEFAULT_ANGLE, DEFAULT_ANGLE)

    def get_pitch_rad(self): return np.deg2rad(self.target_pitch - DEFAULT_ANGLE)
    def get_roll_rad(self): return np.deg2rad(self.target_other - DEFAULT_ANGLE) if GIMBAL_MODE=="PITCH_ROLL" else 0.0

# ================= 初始化 =================
od = ObjectDetection()
od.model.eval()
cam = CameraStream(VIDEO_SOURCE)
height_sensor = HeightSensor(offset_cm=9.3, default_height_m=30.0)

gimbal = None
if SDK_AVAILABLE:
    try:
        ph = PortHandler(DEVICENAME)
        pkt = sms_sts(ph)
        if ph.openPort() and ph.setBaudRate(BAUDRATE):
            print(f"Serial {DEVICENAME} OK")
            gimbal = AsyncMotorController(True, ph, pkt, SERVO_PITCH, SERVO_OTHER)
    except Exception as e:
        print(f"Serial init failed: {e}")
if gimbal is None:
    gimbal = AsyncMotorController(False, None, None, SERVO_PITCH, SERVO_OTHER)

cv2.namedWindow("UAV Tracker", cv2.WINDOW_NORMAL)
cv2.resizeWindow("UAV Tracker", 1280, 720)

tracking = {"selected_id": None, "last_seen": None}
current_boxes = []
fps_window = deque(maxlen=20)
real_height = 30.0
last_height_t = time.perf_counter()

smooth = {"x": DEFAULT_ANGLE, "y": DEFAULT_ANGLE, "prev_x": DEFAULT_ANGLE, "prev_y": DEFAULT_ANGLE}

def make_history():
    kf = KalmanFilter(dim_x=1, dim_z=1)
    kf.x = np.array([[0.]]); kf.F = np.array([[1.]]); kf.H = np.array([[1.]])
    kf.P *= 10.; kf.R = 0.5; kf.Q = 0.01
    return {"px": None, "py": None, "pt": None, "kf": kf, "trail": deque(maxlen=40), "buf": deque(maxlen=4)}
track_history = defaultdict(make_history)

def mouse_callback(event, x, y, flags, param):
    if event == cv2.EVENT_LBUTTONDOWN and current_boxes:
        for b in current_boxes:
            if b["box"][0] <= x <= b["box"][2] and b["box"][1] <= y <= b["box"][3]:
                tracking["selected_id"] = b["id"]
                tracking["last_seen"] = time.perf_counter()
                smooth["x"] = smooth["prev_x"] = DEFAULT_ANGLE
                smooth["y"] = smooth["prev_y"] = DEFAULT_ANGLE
                print(f"Locked ID: {b['id']}")
                return
cv2.setMouseCallback("UAV Tracker", mouse_callback)
print("System started | Anti-jitter params | Target: 12+ FPS")
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

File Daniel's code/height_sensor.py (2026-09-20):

import time
import board
import busio
import adafruit_vl53l0x

class HeightSensor:
    def __init__(self, offset_cm=9.3, default_height_m=30.0):
        """
        :param offset_cm: 传感器光心到相机光心的垂直偏移量(厘米)
        :param default_height_m: 传感器无数据/异常时返回的默认高度(米)
        """
        self.offset_m = offset_cm / 100.0
        self.default_height = default_height_m
        self.vl53 = None
        self._init_sensor()

    def _init_sensor(self):
        try:
            i2c = busio.I2C(board.SCL, board.SDA)
            self.vl53 = adafruit_vl53l0x.VL53L0X(i2c)
            # 提升抗干扰能力（50ms 可滤除部分环境光噪声）
            self.vl53.measurement_timing_budget = 50000  
            print("✅ VL53L0X Height Sensor Initialized")
        except Exception as e:
            print(f"⚠️ VL53L0X Init Failed: {e} | Fallback to {self.default_height}m")
            self.vl53 = None

    def get_height_m(self):
        """返回相机距离地面的实时高度（米），无上下限限制"""
        if self.vl53 is None:
            return self.default_height
        try:
            dist_mm = self.vl53.range  # 单位：毫米
            
            # 🔑 仅过滤无效值：0=未检测到/超量程，<50mm=近场盲区噪声
            # 不再限制上限，传感器能读多少就用多少
            if dist_mm and dist_mm > 50:
                height = (dist_mm / 1000.0) - self.offset_m
                return height  # ✅ 直接返回原始计算值，完全解除限制
            return self.default_height
        except Exception as e:
            print(f"⚠️ Height Read Error: {e}")
            return self.default_height

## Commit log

2026-09-27 Add browser camera preview stream
2026-10-03 Add MaixCAM2 quick-release CAD and two motor bracket versions
    [01_摩擦快拆底座_一体热铆柱.stl, 01_燕尾公件.stl, 02_摩擦快拆底座_M2螺丝固定.stl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]
